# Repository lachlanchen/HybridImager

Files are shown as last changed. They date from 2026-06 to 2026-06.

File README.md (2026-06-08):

[English](README.md) · [العربية](i18n/README.ar.md) · [Español](i18n/README.es.md) · [Français](i18n/README.fr.md) · [日本語](i18n/README.ja.md) · [한국어](i18n/README.ko.md) · [Tiếng Việt](i18n/README.vi.md) · [中文 (简体)](i18n/README.zh-Hans.md) · [中文（繁體）](i18n/README.zh-Hant.md) · [Deutsch](i18n/README.de.md) · [Русский](i18n/README.ru.md)

LazyingArt banner

# HybridImager

*Open hybrid scientific imaging: single-pixel, event, frame, and spectral sensing in one maintainable research stack.*






HybridImager is a research and design workspace for a mixed scientific detector. The concept combines a high-dynamic-range single-pixel bucket detector, event-camera timing, frame-camera texture, and optional spectral measurements under one synchronized data model.

| Donate | PayPal | Stripe |
| --- | --- | --- |
|  |  |  |

## System Concept

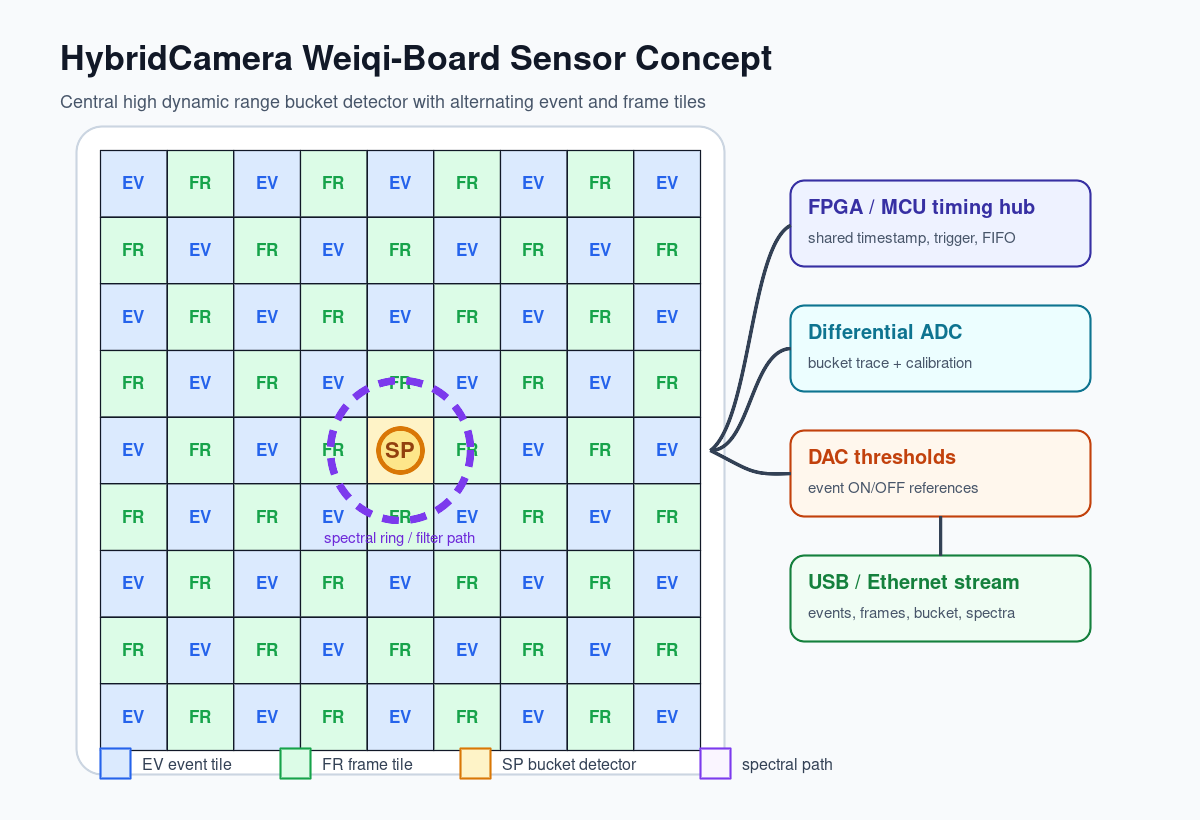
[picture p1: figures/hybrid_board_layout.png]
Hybrid board layout


- **Single-pixel branch:** a central low-noise detector/TIA path for absolute intensity, high dynamic range, and spectral or coded measurements.
- **Event branch:** asynchronous temporal contrast from commercial event cameras first, then open FPGA interfaces when practical.
- **Frame branch:** global-shutter frame modules for texture, calibration, and human-readable inspection.
- **Fusion layer:** timestamped streams with exposure, gain, calibration profile, trigger, and pattern metadata.

## V1 Sensor Board

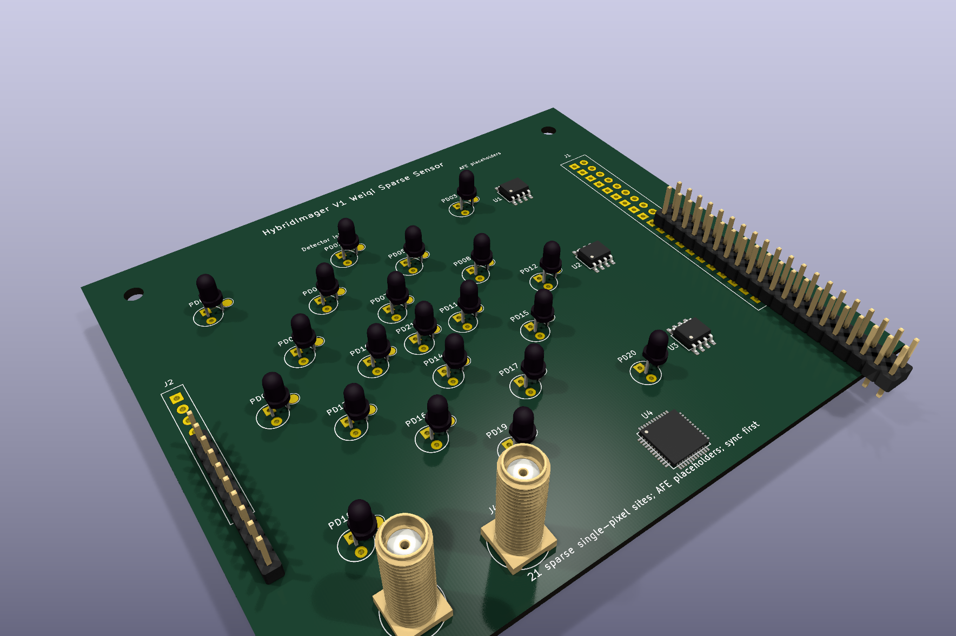
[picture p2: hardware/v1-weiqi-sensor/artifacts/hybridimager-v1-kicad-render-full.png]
HybridImager V1 KiCad render


The first board draft is a KiCad-generated **Weiqi sparse sensor carrier** with 21 single-pixel detector sites, not one central bucket only. It includes per-site signal pads, explicit ground routing, three AFE placeholders, a QFN timing placeholder, SMA sync in/out, power/sync header, and a 2x20 expansion header for later event/frame/tile work.

Review package: [`hardware/v1-weiqi-sensor/`](hardware/v1-weiqi-sensor/) contains the KiCad board, dataset, BOM, clean DRC JSON, STEP model, Gerbers, drill files, and full-view renders.

## V2 ALS-PT19 Matrix

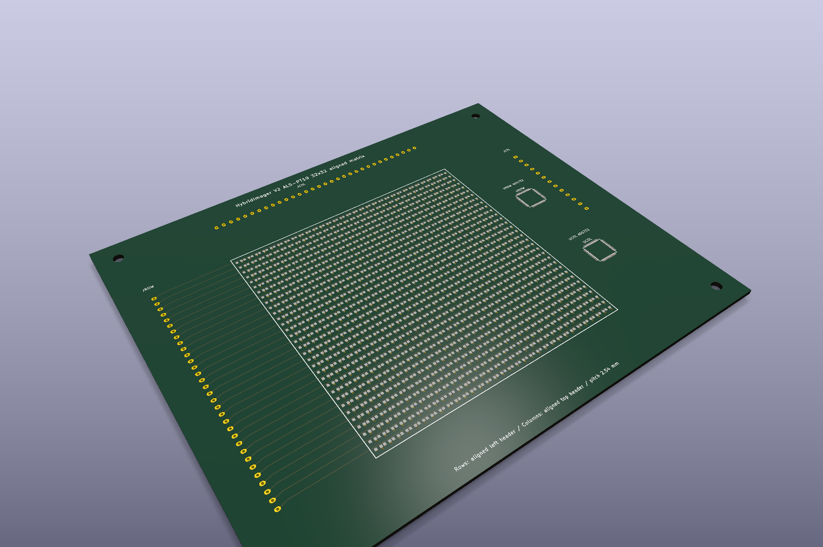
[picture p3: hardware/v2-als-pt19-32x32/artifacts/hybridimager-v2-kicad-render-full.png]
HybridImager V2 KiCad render


V2 is a dense `32x32` sensor-board draft using the `ALS-PT19` phototransistor family from the `CustomSensor`/digiOBSCURA reference. Unlike the older 45-degree, 2.0 mm layout, V2 uses unrotated footprints on a `2.54 mm` pitch so each sensor pad, row header pin, and column header pin is aligned and routable.

Review package: [`hardware/v2-als-pt19-32x32/`](hardware/v2-als-pt19-32x32/) contains the KiCad board, CustomSensor source dataset, BOM, clean DRC JSON, STEP model, Gerbers, drill files, and full-view renders.

## Current Contents

| Area | Location |
| --- | --- |
| Concept paper | `publications/hybrid_camera_concept.pdf` |
| Open camera survey | `publications/open_camera_project_survey.pdf` |
| V1 sparse sensor board | `hardware/v1-weiqi-sensor/` |
| V2 aligned ALS-PT19 matrix | `hardware/v2-als-pt19-32x32/` |
| Research notes | `references/` |
| Deterministic diagrams | `figures/hybrid_board_layout.*`, `figures/hybrid_signal_chain.*` |
| Hardware plan | `hardware/board_architecture.md` |
| Reconstruction plan | `algorithms/reconstruction_plan.md` |
| Prior context | `copied-context/` |
| Open project mirrors | `external/` as git submodules |

## Quick Start

```bash
git clone --recurse-submodules https://github.com/lachlanchen/HybridImager.git
cd HybridImager
make all
```

If the repository is already cloned:

```bash
git submodule update --init --recursive
make survey
```

## Research Baseline

The strongest open single-pixel path is **ONE-PIX** plus **ONE-PIX_hardware**. For event vision, the realistic first build uses commercial event cameras with **OpenEB**, **jAER**, **v2e**, and **E2VID**. For frame hardware, the useful open references are **OneInchEye**, **Antmicro OV9281**, **AXIOM Beta**, and **Seeed reCamera**.

The project does not assume a custom event-sensor ASIC in the first stage. It starts with open board-level synchronization, open data formats, open reconstruction, and reusable mechanical/PCB references.

## CAD And Hardware Notes

Preferred Shapr3D export package for editable mechanical work:

```text
STEP + native .shapr + Parasolid + DXF from sketch + 3MF/STL preview
```

Use STEP as the main interchange format, Parasolid as the high-fidelity solid backup, DXF for 2D outlines and plates, and STL/3MF only for print or mesh preview.

## Build Commands

```bash
make figures   # regenerate deterministic diagrams
make paper     # compile the HybridImager concept paper
make survey    # compile the open camera project survey
make all       # run paper and survey builds
make clean     # remove LaTeX build byproducts
```

## Citation

If you use HybridImager in research, cite the repository. GitHub reads [CITATION.cff](CITATION.cff) and shows a **Cite this repository** panel on the repo page.

```bibtex
@software{chen_hybridimager_2026,
  author = {Chen, Lachlan},
  title = {HybridImager: Open Hybrid Scientific Imaging Research Workspace},
  year = {2026},
  url = {https://github.com/lachlanchen/HybridImager}
}
```

## Status

This is an early research workspace, not a certified imaging product. The immediate goal is a maintainable experiment pipeline for optical and microscopy setups: build with available modules, synchronize cleanly, reconstruct reproducibly, and only integrate custom hardware after the data contract is stable.

Build less. Image more.

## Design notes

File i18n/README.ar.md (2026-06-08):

[English](../README.md) · [العربية](README.ar.md) · [Español](README.es.md) · [Français](README.fr.md) · [日本語](README.ja.md) · [한국어](README.ko.md) · [Tiếng Việt](README.vi.md) · [中文 (简体)](README.zh-Hans.md) · [中文（繁體）](README.zh-Hant.md) · [Deutsch](README.de.md) · [Русский](README.ru.md)

LazyingArt banner

# HybridImager

*تصوير علمي هجين ومفتوح: بكسل واحد، وأحداث، وإطارات، وقياس طيفي ضمن حزمة بحثية قابلة للصيانة.*






HybridImager مساحة بحث وتصميم لكاشف علمي مختلط. يجمع المفهوم بين كاشف بكسل واحد عالي المجال الديناميكي، وتوقيت كاميرا الأحداث، وملمس كاميرا الإطارات، وقياسات طيفية اختيارية ضمن نموذج بيانات متزامن واحد.

| Donate | PayPal | Stripe |
| --- | --- | --- |
|  |  |  |

## مفهوم النظام

Hybrid board layout

- **فرع البكسل الواحد:** مسار كاشف ومضخم TIA منخفض الضجيج للكثافة المطلقة، والمجال الديناميكي العالي، والقياسات الطيفية أو المرمزة.
- **فرع الأحداث:** تباين زمني غير متزامن من كاميرات أحداث تجارية أولا، ثم واجهات FPGA مفتوحة عندما يصبح ذلك عمليا.
- **فرع الإطارات:** وحدات إطارات ذات غالق عام للملمس، والمعايرة، والفحص البشري.
- **طبقة الدمج:** تدفقات ذات طابع زمني مع التعريض، والكسب، وملف المعايرة، والمشغل، وبيانات النمط.

## لوحة المستشعر V1

عرض KiCad لـ HybridImager V1

المسودة الأولى للوحة هي حاملة مستشعرات متناثرة بنمط **Weiqi** مولدة في KiCad، وفيها 21 موقع كاشف بكسل واحد بدلا من bucket مركزي واحد فقط. تتضمن Pads إشارة لكل موقع، ومسار أرضي واضحا، وثلاثة مواضع AFE، وموضع توقيت QFN، وSMA للمزامنة دخولا وخروجا، وموصل طاقة/مزامنة، وموصل توسعة 2x20.

حزمة المراجعة: [`hardware/v1-weiqi-sensor/`](../hardware/v1-weiqi-sensor/) تحتوي لوحة KiCad، ومجموعة البيانات، وBOM، وDRC نظيفا، وSTEP، وGerbers، وملفات الحفر، وعروض الرؤية الكاملة.

## المحتوى الحالي

| المجال | الموقع |
| --- | --- |
| ورقة المفهوم | `publications/hybrid_camera_concept.pdf` |
| مسح مشاريع الكاميرات المفتوحة | `publications/open_camera_project_survey.pdf` |
| لوحة مستشعر متناثرة V1 | `hardware/v1-weiqi-sensor/` |
| مصفوفة ALS-PT19 مصطفة V2 | `hardware/v2-als-pt19-32x32/` |
| ملاحظات البحث | `references/` |
| الرسوم الحتمية | `figures/hybrid_board_layout.*`, `figures/hybrid_signal_chain.*` |
| خطة العتاد | `hardware/board_architecture.md` |
| خطة إعادة البناء | `algorithms/reconstruction_plan.md` |
| سياق سابق | `copied-context/` |
| مرايا المشاريع المفتوحة | `external/` كوحدات git فرعية |

## البدء السريع

```bash
git clone --recurse-submodules https://github.com/lachlanchen/HybridImager.git
cd HybridImager
make all
```

إذا كان المستودع مستنسخا مسبقا:

```bash
git submodule update --init --recursive
make survey
```

## خط الأساس البحثي

أقوى مسار مفتوح للبكسل الواحد هو **ONE-PIX** مع **ONE-PIX_hardware**. ولرؤية الأحداث، يبدأ البناء الواقعي بكاميرات أحداث تجارية مع **OpenEB** و **jAER** و **v2e** و **E2VID**. أما عتاد الإطارات، فأفضل المراجع المفتوحة هي **OneInchEye** و **Antmicro OV9281** و **AXIOM Beta** و **Seeed reCamera**.

لا يفترض المشروع تصنيع ASIC مخصص لحساس الأحداث في المرحلة الأولى. يبدأ بالمزامنة المفتوحة على مستوى اللوحة، وصيغ البيانات المفتوحة، وإعادة البناء القابلة للتكرار، ومراجع ميكانيكية ومراجع PCB قابلة لإعادة الاستخدام.

## ملاحظات CAD والعتاد

حزمة التصدير المفضلة من Shapr3D للعمل الميكانيكي القابل للتحرير:

```text
STEP + native .shapr + Parasolid + DXF from sketch + 3MF/STL preview
```

استخدم STEP كصيغة تبادل رئيسية، وParasolid كنسخة صلبة احتياطية عالية الدقة، وDXF للمخططات ثنائية الأبعاد والصفائح، وSTL/3MF للطباعة أو معاينة الشبكات فقط.

## أوامر البناء

```bash
make figures
make paper
make survey
make all
make clean
```

## الاستشهاد

إذا استخدمت HybridImager في بحثك، فاستشهد بالمستودع. يقرأ GitHub ملف [CITATION.cff](../CITATION.cff) ويعرض لوحة **Cite this repository** في صفحة المستودع.

```bibtex
@software{chen_hybridimager_2026,
  author = {Chen, Lachlan},
  title = {HybridImager: Open Hybrid Scientific Imaging Research Workspace},
  year = {2026},
  url = {https://github.com/lachlanchen/HybridImager}
}
```

## الحالة

هذه مساحة بحث مبكرة وليست منتجا تصويريا معتمدا. الهدف المباشر هو خط تجارب قابل للصيانة للأنظمة البصرية والمجهرية: البناء بوحدات متاحة، والمزامنة النظيفة، وإعادة البناء القابلة للتكرار، ثم دمج العتاد المخصص فقط بعد استقرار عقد البيانات.

ابن أقل. صوّر أكثر.

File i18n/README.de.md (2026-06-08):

[English](../README.md) · [العربية](README.ar.md) · [Español](README.es.md) · [Français](README.fr.md) · [日本語](README.ja.md) · [한국어](README.ko.md) · [Tiếng Việt](README.vi.md) · [中文 (简体)](README.zh-Hans.md) · [中文（繁體）](README.zh-Hant.md) · [Deutsch](README.de.md) · [Русский](README.ru.md)

LazyingArt banner

# HybridImager

*Offene hybride wissenschaftliche Bildgebung: Einzelpixel, Events, Frames und Spektren in einem wartbaren Forschungs-Stack.*






HybridImager ist ein Forschungs- und Design-Arbeitsbereich für einen gemischten wissenschaftlichen Detektor. Das Konzept kombiniert einen Einzelpixel-Bucket-Detektor mit hohem Dynamikumfang, Event-Kamera-Timing, Frame-Kamera-Textur und optionale Spektralmessungen in einem synchronisierten Datenmodell.

| Donate | PayPal | Stripe |
| --- | --- | --- |
|  |  |  |

## Systemkonzept

Hybrid board layout

- **Einzelpixel-Zweig:** zentraler rauscharmer Detektor/TIA-Pfad für absolute Intensität, hohen Dynamikumfang und spektrale oder codierte Messungen.
- **Event-Zweig:** asynchroner zeitlicher Kontrast zuerst mit kommerziellen Event-Kameras, später mit offenen FPGA-Schnittstellen.
- **Frame-Zweig:** Global-Shutter-Module für Textur, Kalibrierung und menschlich lesbare Kontrolle.
- **Fusionsschicht:** Zeitgestempelte Streams mit Belichtung, Gain, Kalibrierprofil, Trigger und Pattern-Metadaten.

## V1-Sensorplatine

HybridImager V1 KiCad-Render

Der erste Platinendraft ist ein in KiCad erzeugter **Weiqi**-Sparse-Sensorträger mit 21 Einzelpixel-Detektorpositionen, nicht nur einem zentralen Bucket. Er enthält Signalpads pro Position, explizite Masseführung, drei AFE-Platzhalter, einen QFN-Timing-Platzhalter, SMA-Sync-Anschlüsse, eine Power/Sync-Stiftleiste und eine 2x20-Erweiterung.

Review-Paket: [`hardware/v1-weiqi-sensor/`](../hardware/v1-weiqi-sensor/) enthält KiCad-Board, Dataset, BOM, sauberen DRC, STEP, Gerbers, Bohrdaten und Vollansicht-Renderings.

## Aktueller Inhalt

| Bereich | Ort |
| --- | --- |
| Konzeptpapier | `publications/hybrid_camera_concept.pdf` |
| Open-Camera-Studie | `publications/open_camera_project_survey.pdf` |
| V1-Sparse-Sensorplatine | `hardware/v1-weiqi-sensor/` |
| V2 ausgerichtete ALS-PT19-Matrix | `hardware/v2-als-pt19-32x32/` |
| Forschungsnotizen | `references/` |
| Deterministische Diagramme | `figures/hybrid_board_layout.*`, `figures/hybrid_signal_chain.*` |
| Hardwareplan | `hardware/board_architecture.md` |
| Rekonstruktionsplan | `algorithms/reconstruction_plan.md` |
| Vorheriger Kontext | `copied-context/` |
| Spiegel offener Projekte | `external/` als git submodules |

## Schnellstart

```bash
git clone --recurse-submodules https://github.com/lachlanchen/HybridImager.git
cd HybridImager
make all
```

Wenn das Repository bereits geklont ist:

```bash
git submodule update --init --recursive
make survey
```

## Forschungsbasis

Der stärkste offene Einzelpixel-Pfad ist **ONE-PIX** plus **ONE-PIX_hardware**. Für Event Vision nutzt der realistische erste Aufbau kommerzielle Event-Kameras mit **OpenEB**, **jAER**, **v2e** und **E2VID**. Für Frame-Hardware sind **OneInchEye**, **Antmicro OV9281**, **AXIOM Beta** und **Seeed reCamera** nützliche offene Referenzen.

Das Projekt setzt in der ersten Phase keinen eigenen Event-Sensor-ASIC voraus. Es beginnt mit offener Board-Synchronisation, offenen Datenformaten, reproduzierbarer Rekonstruktion und wiederverwendbaren Mechanik- und PCB-Referenzen.

## CAD- und Hardware-Hinweise

Bevorzugtes Shapr3D-Exportpaket für editierbare Mechanik:

```text
STEP + native .shapr + Parasolid + DXF from sketch + 3MF/STL preview
```

STEP ist das Hauptaustauschformat, Parasolid die hochgenaue Solid-Sicherung, DXF dient 2D-Konturen und Platten, STL/3MF nur Druck oder Mesh-Vorschau.

## Build-Befehle

```bash
make figures
make paper
make survey
make all
make clean
```

## Zitieren

Wenn Sie HybridImager in Forschung verwenden, zitieren Sie bitte dieses Repository. GitHub liest [CITATION.cff](../CITATION.cff) und zeigt auf der Repository-Seite das Panel **Cite this repository** an.

```bibtex
@software{chen_hybridimager_2026,
  author = {Chen, Lachlan},
  title = {HybridImager: Open Hybrid Scientific Imaging Research Workspace},
  year = {2026},
  url = {https://github.com/lachlanchen/HybridImager}
}
```

## Status

Dies ist ein früher Forschungsarbeitsbereich, kein zertifiziertes Bildgebungsprodukt. Das unmittelbare Ziel ist eine wartbare Experiment-Pipeline für Optik und Mikroskopie: mit verfügbaren Modulen bauen, sauber synchronisieren, reproduzierbar rekonstruieren und kundenspezifische Hardware erst integrieren, wenn der Datenvertrag stabil ist.

Weniger bauen. Mehr abbilden.

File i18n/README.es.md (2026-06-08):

[English](../README.md) · [العربية](README.ar.md) · [Español](README.es.md) · [Français](README.fr.md) · [日本語](README.ja.md) · [한국어](README.ko.md) · [Tiếng Việt](README.vi.md) · [中文 (简体)](README.zh-Hans.md) · [中文（繁體）](README.zh-Hant.md) · [Deutsch](README.de.md) · [Русский](README.ru.md)

LazyingArt banner

# HybridImager

*Imagen científica híbrida y abierta: píxel único, eventos, fotogramas y espectro en una pila de investigación mantenible.*






HybridImager es un espacio de investigación y diseño para un detector científico mixto. Combina un detector de píxel único de alto rango dinámico, temporización de cámara de eventos, textura de cámara de fotogramas y mediciones espectrales opcionales bajo un modelo de datos sincronizado.

| Donate | PayPal | Stripe |
| --- | --- | --- |
|  |  |  |

## Concepto del sistema

Hybrid board layout

- **Rama de píxel único:** detector central y TIA de bajo ruido para intensidad absoluta, alto rango dinámico y mediciones codificadas o espectrales.
- **Rama de eventos:** contraste temporal asíncrono con cámaras comerciales al inicio y luego interfaces FPGA abiertas cuando sea práctico.
- **Rama de fotogramas:** módulos de obturador global para textura, calibración e inspección visual.
- **Capa de fusión:** flujos temporizados con exposición, ganancia, perfil de calibración, disparo y metadatos de patrón.

## Placa sensora V1

Render KiCad de HybridImager V1

El primer borrador de placa es un portador sensor disperso tipo **Weiqi** generado en KiCad, con 21 sitios de detector de píxel único y no un único bucket central. Incluye pads de señal por sitio, retorno de tierra explícito, tres placeholders AFE, un placeholder QFN de temporización, SMA de sincronización, cabecera de alimentación/sync y expansión 2x20.

Paquete de revisión: [`hardware/v1-weiqi-sensor/`](../hardware/v1-weiqi-sensor/) contiene la placa KiCad, dataset, BOM, DRC limpio, STEP, Gerbers, taladros y renders completos.

## Contenido actual

| Área | Ubicación |
| --- | --- |
| Artículo conceptual | `publications/hybrid_camera_concept.pdf` |
| Revisión de cámaras abiertas | `publications/open_camera_project_survey.pdf` |
| Placa sensora dispersa V1 | `hardware/v1-weiqi-sensor/` |
| Matriz ALS-PT19 alineada V2 | `hardware/v2-als-pt19-32x32/` |
| Notas de investigación | `references/` |
| Diagramas deterministas | `figures/hybrid_board_layout.*`, `figures/hybrid_signal_chain.*` |
| Plan de hardware | `hardware/board_architecture.md` |
| Plan de reconstrucción | `algorithms/reconstruction_plan.md` |
| Contexto previo | `copied-context/` |
| Espejos de proyectos abiertos | `external/` como submódulos git |

## Inicio rápido

```bash
git clone --recurse-submodules https://github.com/lachlanchen/HybridImager.git
cd HybridImager
make all
```

Si ya está clonado:

```bash
git submodule update --init --recursive
make survey
```

## Base de investigación

La ruta abierta más sólida para píxel único es **ONE-PIX** con **ONE-PIX_hardware**. Para visión de eventos, el primer prototipo realista usa cámaras comerciales con **OpenEB**, **jAER**, **v2e** y **E2VID**. Para hardware de fotogramas, las referencias abiertas útiles son **OneInchEye**, **Antmicro OV9281**, **AXIOM Beta** y **Seeed reCamera**.

El proyecto no presupone un ASIC personalizado de eventos en la primera etapa. Empieza con sincronización abierta a nivel de placa, formatos de datos abiertos, reconstrucción reproducible y referencias reutilizables de mecánica y PCB.

## Notas CAD y hardware

Paquete de exportación preferido desde Shapr3D para trabajo mecánico editable:

```text
STEP + native .shapr + Parasolid + DXF from sketch + 3MF/STL preview
```

Use STEP como formato principal, Parasolid como respaldo sólido de alta fidelidad, DXF para contornos 2D y placas, y STL/3MF solo para impresión o vista de malla.

## Comandos de compilación

```bash
make figures
make paper
make survey
make all
make clean
```

## Cita

Si usas HybridImager en investigación, cita el repositorio. GitHub lee [CITATION.cff](../CITATION.cff) y muestra el panel **Cite this repository** en la página del repositorio.

```bibtex
@software{chen_hybridimager_2026,
  author = {Chen, Lachlan},
  title = {HybridImager: Open Hybrid Scientific Imaging Research Workspace},
  year = {2026},
  url = {https://github.com/lachlanchen/HybridImager}
}
```

## Estado

Este es un espacio de investigación temprano, no un producto de imagen certificado. El objetivo inmediato es una tubería experimental mantenible para óptica y microscopía: construir con módulos disponibles, sincronizar limpiamente, reconstruir de forma reproducible e integrar hardware personalizado solo cuando el contrato de datos sea estable.

Construye menos. Imagen más.

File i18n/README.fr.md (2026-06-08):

[English](../README.md) · [العربية](README.ar.md) · [Español](README.es.md) · [Français](README.fr.md) · [日本語](README.ja.md) · [한국어](README.ko.md) · [Tiếng Việt](README.vi.md) · [中文 (简体)](README.zh-Hans.md) · [中文（繁體）](README.zh-Hant.md) · [Deutsch](README.de.md) · [Русский](README.ru.md)

LazyingArt banner

# HybridImager

*Imagerie scientifique hybride et ouverte : pixel unique, événements, images et spectre dans une pile de recherche maintenable.*






HybridImager est un espace de recherche et de conception pour un détecteur scientifique mixte. Il associe un détecteur à pixel unique à grande dynamique, le timing d'une caméra événementielle, la texture d'une caméra à images et des mesures spectrales optionnelles dans un même modèle de données synchronisé.

| Donate | PayPal | Stripe |
| --- | --- | --- |
|  |  |  |

## Concept du système

Hybrid board layout

- **Branche pixel unique :** détecteur central et TIA faible bruit pour l'intensité absolue, la grande dynamique et les mesures spectrales ou codées.
- **Branche événementielle :** contraste temporel asynchrone avec des caméras commerciales d'abord, puis des interfaces FPGA ouvertes lorsque cela devient pratique.
- **Branche image :** modules à obturateur global pour la texture, la calibration et l'inspection lisible.
- **Couche de fusion :** flux horodatés avec exposition, gain, profil de calibration, déclenchement et métadonnées de motif.

## Carte capteur V1

Rendu KiCad de HybridImager V1

Le premier brouillon de carte est un support capteur clairsemé de type **Weiqi**, généré avec KiCad, avec 21 sites de détecteur à pixel unique plutôt qu'un seul bucket central. Il inclut des pads de signal par site, un retour de masse explicite, trois emplacements AFE, un emplacement QFN de temporisation, des SMA de synchronisation, un connecteur alimentation/sync et une extension 2x20.

Paquet de revue : [`hardware/v1-weiqi-sensor/`](../hardware/v1-weiqi-sensor/) contient la carte KiCad, le dataset, la BOM, le DRC propre, le STEP, les Gerbers, les perçages et les rendus complets.

## Contenu actuel

| Zone | Emplacement |
| --- | --- |
| Article conceptuel | `publications/hybrid_camera_concept.pdf` |
| Revue des caméras ouvertes | `publications/open_camera_project_survey.pdf` |
| Carte capteur clairsemée V1 | `hardware/v1-weiqi-sensor/` |
| Matrice ALS-PT19 alignée V2 | `hardware/v2-als-pt19-32x32/` |
| Notes de recherche | `references/` |
| Diagrammes déterministes | `figures/hybrid_board_layout.*`, `figures/hybrid_signal_chain.*` |
| Plan matériel | `hardware/board_architecture.md` |
| Plan de reconstruction | `algorithms/reconstruction_plan.md` |
| Contexte antérieur | `copied-context/` |
| Miroirs de projets ouverts | `external/` comme sous-modules git |

## Démarrage rapide

```bash
git clone --recurse-submodules https://github.com/lachlanchen/HybridImager.git
cd HybridImager
make all
```

Si le dépôt est déjà cloné :

```bash
git submodule update --init --recursive
make survey
```

## Base de recherche

La voie ouverte la plus solide pour le pixel unique est **ONE-PIX** avec **ONE-PIX_hardware**. Pour la vision événementielle, le premier montage réaliste utilise des caméras commerciales avec **OpenEB**, **jAER**, **v2e** et **E2VID**. Pour le matériel image, les références ouvertes utiles sont **OneInchEye**, **Antmicro OV9281**, **AXIOM Beta** et **Seeed reCamera**.

Le projet ne suppose pas un ASIC événementiel personnalisé dès la première étape. Il commence par une synchronisation ouverte au niveau carte, des formats de données ouverts, une reconstruction reproductible et des références mécaniques/PCB réutilisables.

## Notes CAD et matériel

Paquet d'export Shapr3D préféré pour le travail mécanique éditable :

```text
STEP + native .shapr + Parasolid + DXF from sketch + 3MF/STL preview
```

Utilisez STEP comme format principal, Parasolid comme sauvegarde solide haute fidélité, DXF pour les contours 2D et les plaques, et STL/3MF seulement pour l'impression ou la prévisualisation de maillage.

## Commandes de construction

```bash
make figures
make paper
make survey
make all
make clean
```

## Citation

Si vous utilisez HybridImager dans une recherche, citez le dépôt. GitHub lit [CITATION.cff](../CITATION.cff) et affiche le panneau **Cite this repository** sur la page du dépôt.

```bibtex
@software{chen_hybridimager_2026,
  author = {Chen, Lachlan},
  title = {HybridImager: Open Hybrid Scientific Imaging Research Workspace},
  year = {2026},
  url = {https://github.com/lachlanchen/HybridImager}
}
```

## Statut

C'est un espace de recherche précoce, pas un produit d'imagerie certifié. L'objectif immédiat est une chaîne expérimentale maintenable pour l'optique et la microscopie : construire avec des modules disponibles, synchroniser proprement, reconstruire de manière reproductible, puis intégrer du matériel personnalisé seulement lorsque le contrat de données est stable.

Construire moins. Imager plus.

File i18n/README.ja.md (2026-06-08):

[English](../README.md) · [العربية](README.ar.md) · [Español](README.es.md) · [Français](README.fr.md) · [日本語](README.ja.md) · [한국어](README.ko.md) · [Tiếng Việt](README.vi.md) · [中文 (简体)](README.zh-Hans.md) · [中文（繁體）](README.zh-Hant.md) · [Deutsch](README.de.md) · [Русский](README.ru.md)

LazyingArt banner

# HybridImager

*単一画素、イベント、フレーム、スペクトル計測を一つの保守しやすい研究スタックにまとめる、オープンなハイブリッド科学イメージング。*






HybridImager は、混合型科学検出器のための研究・設計ワークスペースです。高ダイナミックレンジの単一画素バケット検出器、イベントカメラのタイミング、フレームカメラのテクスチャ、任意のスペクトル測定を、一つの同期データモデルで扱います。

| Donate | PayPal | Stripe |
| --- | --- | --- |
|  |  |  |

## システム概念

Hybrid board layout

- **単一画素ブランチ:** 絶対強度、高ダイナミックレンジ、スペクトルまたは符号化測定のための中央低ノイズ検出器/TIA 経路。
- **イベントブランチ:** まず商用イベントカメラで非同期の時間コントラストを使い、実用化できる段階でオープンな FPGA インターフェイスへ進む。
- **フレームブランチ:** テクスチャ、較正、人が読める確認のためのグローバルシャッターフレームモジュール。
- **融合レイヤー:** 露光、ゲイン、較正プロファイル、トリガー、パターン情報を含むタイムスタンプ付きストリーム。

## V1 センサーボード

HybridImager V1 KiCad レンダー

最初の基板ドラフトは KiCad で生成した **囲碁風の疎なセンサーキャリア**で、中央の bucket 1個だけではなく 21 個の単一画素検出器サイトを持ちます。各サイトの信号パッド、明示的なグラウンド配線、3 個の AFE プレースホルダー、QFN タイミングプレースホルダー、SMA 同期入出力、電源/同期ヘッダー、2x20 拡張ヘッダーを含みます。

レビューパッケージ: [`hardware/v1-weiqi-sensor/`](../hardware/v1-weiqi-sensor/) には KiCad 基板、データセット、BOM、クリーンな DRC、STEP、Gerber、ドリルファイル、全体レンダーが含まれます。

## 現在の内容

| 領域 | 場所 |
| --- | --- |
| コンセプト論文 | `publications/hybrid_camera_concept.pdf` |
| オープンカメラ調査 | `publications/open_camera_project_survey.pdf` |
| V1 疎センサーボード | `hardware/v1-weiqi-sensor/` |
| V2 整列 ALS-PT19 マトリクス | `hardware/v2-als-pt19-32x32/` |
| 研究ノート | `references/` |
| 決定的に生成される図 | `figures/hybrid_board_layout.*`, `figures/hybrid_signal_chain.*` |
| ハードウェア計画 | `hardware/board_architecture.md` |
| 再構成計画 | `algorithms/reconstruction_plan.md` |
| 以前の文脈 | `copied-context/` |
| オープンプロジェクトのミラー | `external/` の git submodule |

## クイックスタート

```bash
git clone --recurse-submodules https://github.com/lachlanchen/HybridImager.git
cd HybridImager
make all
```

すでに clone 済みの場合:

```bash
git submodule update --init --recursive
make survey
```

## 研究ベースライン

単一画素の最も強いオープン経路は **ONE-PIX** と **ONE-PIX_hardware** です。イベントビジョンでは、最初の現実的な構成として商用イベントカメラと **OpenEB**、**jAER**、**v2e**、**E2VID** を使います。フレームハードウェアでは **OneInchEye**、**Antmicro OV9281**、**AXIOM Beta**、**Seeed reCamera** が有用なオープン参照です。

このプロジェクトは初期段階からカスタムイベントセンサー ASIC を前提にしません。まず基板レベルの同期、オープンなデータ形式、再現可能な再構成、再利用できる機械/PCB 参照から始めます。

## CAD とハードウェアの注意

編集可能な機械設計に推奨する Shapr3D の出力:

```text
STEP + native .shapr + Parasolid + DXF from sketch + 3MF/STL preview
```

STEP を主な交換形式、Parasolid を高忠実度のソリッドバックアップ、DXF を 2D 外形や板材用、STL/3MF を印刷またはメッシュプレビュー専用として使います。

## ビルドコマンド

```bash
make figures
make paper
make survey
make all
make clean
```

## 引用

研究で HybridImager を使用する場合は、このリポジトリを引用してください。GitHub は [CITATION.cff](../CITATION.cff) を読み取り、リポジトリページに **Cite this repository** パネルを表示します。

```bibtex
@software{chen_hybridimager_2026,
  author = {Chen, Lachlan},
  title = {HybridImager: Open Hybrid Scientific Imaging Research Workspace},
  year = {2026},
  url = {https://github.com/lachlanchen/HybridImager}
}
```

## 状態

これは初期研究ワークスペースであり、認証済みのイメージング製品ではありません。直近の目的は、光学・顕微鏡実験のための保守可能なパイプラインを作ることです。入手可能なモジュールで構築し、きれいに同期し、再現可能に再構成し、データ契約が安定してから専用ハードウェアを統合します。

少なく作る。もっと撮る。

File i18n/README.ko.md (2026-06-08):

[English](../README.md) · [العربية](README.ar.md) · [Español](README.es.md) · [Français](README.fr.md) · [日本語](README.ja.md) · [한국어](README.ko.md) · [Tiếng Việt](README.vi.md) · [中文 (简体)](README.zh-Hans.md) · [中文（繁體）](README.zh-Hant.md) · [Deutsch](README.de.md) · [Русский](README.ru.md)

LazyingArt banner

# HybridImager

*단일 픽셀, 이벤트, 프레임, 스펙트럼 감지를 하나의 유지 가능한 연구 스택으로 묶는 오픈 하이브리드 과학 이미징.*






HybridImager는 혼합 과학 검출기를 위한 연구 및 설계 작업 공간입니다. 고동적 범위 단일 픽셀 버킷 검출기, 이벤트 카메라 타이밍, 프레임 카메라 텍스처, 선택적 스펙트럼 측정을 하나의 동기화된 데이터 모델로 결합합니다.

| Donate | PayPal | Stripe |
| --- | --- | --- |
|  |  |  |

## 시스템 개념

Hybrid board layout

- **단일 픽셀 브랜치:** 절대 강도, 고동적 범위, 스펙트럼 또는 부호화 측정을 위한 중앙 저잡음 검출기/TIA 경로입니다.
- **이벤트 브랜치:** 먼저 상용 이벤트 카메라로 비동기 시간 대비를 사용하고, 가능해지면 오픈 FPGA 인터페이스로 확장합니다.
- **프레임 브랜치:** 텍스처, 보정, 사람이 확인할 수 있는 검사를 위한 글로벌 셔터 프레임 모듈입니다.
- **퓨전 레이어:** 노출, 게인, 보정 프로파일, 트리거, 패턴 메타데이터를 포함하는 타임스탬프 스트림입니다.

## V1 센서 보드

HybridImager V1 KiCad 렌더

첫 번째 보드 초안은 KiCad로 생성한 **바둑판형 희소 센서 캐리어**이며, 중앙 bucket 하나만이 아니라 21개의 단일 픽셀 검출기 사이트를 둡니다. 사이트별 신호 패드, 명시적 접지 배선, AFE 플레이스홀더 3개, QFN 타이밍 플레이스홀더, SMA 동기 입출력, 전원/동기 헤더, 2x20 확장 헤더를 포함합니다.

검토 패키지: [`hardware/v1-weiqi-sensor/`](../hardware/v1-weiqi-sensor/)에는 KiCad 보드, 데이터셋, BOM, 깨끗한 DRC, STEP, Gerber, 드릴 파일, 전체 렌더가 포함됩니다.

## 현재 내용

| 영역 | 위치 |
| --- | --- |
| 개념 논문 | `publications/hybrid_camera_concept.pdf` |
| 오픈 카메라 조사 | `publications/open_camera_project_survey.pdf` |
| V1 희소 센서 보드 | `hardware/v1-weiqi-sensor/` |
| V2 정렬 ALS-PT19 매트릭스 | `hardware/v2-als-pt19-32x32/` |
| 연구 노트 | `references/` |
| 결정론적 다이어그램 | `figures/hybrid_board_layout.*`, `figures/hybrid_signal_chain.*` |
| 하드웨어 계획 | `hardware/board_architecture.md` |
| 재구성 계획 | `algorithms/reconstruction_plan.md` |
| 이전 맥락 | `copied-context/` |
| 오픈 프로젝트 미러 | `external/` git submodule |

## 빠른 시작

```bash
git clone --recurse-submodules https://github.com/lachlanchen/HybridImager.git
cd HybridImager
make all
```

이미 클론한 경우:

```bash
git submodule update --init --recursive
make survey
```

## 연구 기준선

가장 강한 오픈 단일 픽셀 경로는 **ONE-PIX**와 **ONE-PIX_hardware**입니다. 이벤트 비전의 현실적인 첫 빌드는 상용 이벤트 카메라와 **OpenEB**, **jAER**, **v2e**, **E2VID**를 사용합니다. 프레임 하드웨어에는 **OneInchEye**, **Antmicro OV9281**, **AXIOM Beta**, **Seeed reCamera**가 유용한 오픈 참고 자료입니다.

이 프로젝트는 첫 단계에서 맞춤형 이벤트 센서 ASIC을 전제로 하지 않습니다. 먼저 보드 수준 동기화, 오픈 데이터 형식, 재현 가능한 재구성, 재사용 가능한 기계/PCB 참고 자료에서 시작합니다.

## CAD 및 하드웨어 노트

편집 가능한 기계 작업을 위한 Shapr3D 권장 내보내기 패키지:

```text
STEP + native .shapr + Parasolid + DXF from sketch + 3MF/STL preview
```

STEP은 기본 교환 형식, Parasolid는 고충실도 솔리드 백업, DXF는 2D 외곽선과 판재, STL/3MF는 출력 또는 메시 미리보기 전용으로 사용합니다.

## 빌드 명령

```bash
make figures
make paper
make survey
make all
make clean
```

## 인용

연구에서 HybridImager를 사용한다면 이 저장소를 인용하세요. GitHub는 [CITATION.cff](../CITATION.cff)를 읽어 저장소 페이지에 **Cite this repository** 패널을 표시합니다.

```bibtex
@software{chen_hybridimager_2026,
  author = {Chen, Lachlan},
  title = {HybridImager: Open Hybrid Scientific Imaging Research Workspace},
  year = {2026},
  url = {https://github.com/lachlanchen/HybridImager}
}
```

## 상태

이 저장소는 초기 연구 작업 공간이며 인증된 이미징 제품이 아닙니다. 즉각적인 목표는 광학 및 현미경 실험을 위한 유지 가능한 파이프라인입니다. 사용 가능한 모듈로 만들고, 깨끗하게 동기화하고, 재현 가능하게 재구성하며, 데이터 계약이 안정된 뒤에만 맞춤형 하드웨어를 통합합니다.

덜 만들고, 더 많이 이미징합니다.

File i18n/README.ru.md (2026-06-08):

[English](../README.md) · [العربية](README.ar.md) · [Español](README.es.md) · [Français](README.fr.md) · [日本語](README.ja.md) · [한국어](README.ko.md) · [Tiếng Việt](README.vi.md) · [中文 (简体)](README.zh-Hans.md) · [中文（繁體）](README.zh-Hant.md) · [Deutsch](README.de.md) · [Русский](README.ru.md)

LazyingArt banner

# HybridImager

*Открытая гибридная научная визуализация: один пиксель, события, кадры и спектр в поддерживаемом исследовательском стеке.*






HybridImager — это исследовательская и проектная среда для смешанного научного детектора. Концепция объединяет однопиксельный bucket-детектор с высоким динамическим диапазоном, тайминг событийной камеры, текстуру кадровой камеры и дополнительные спектральные измерения в одной синхронизированной модели данных.

| Donate | PayPal | Stripe |
| --- | --- | --- |
|  |  |  |

## Концепция системы

Hybrid board layout

- **Однопиксельная ветка:** центральный малошумящий детектор/TIA для абсолютной интенсивности, высокого динамического диапазона, спектральных или кодированных измерений.
- **Событийная ветка:** асинхронный временной контраст сначала с коммерческими событийными камерами, затем с открытыми FPGA-интерфейсами.
- **Кадровая ветка:** модули с глобальным затвором для текстуры, калибровки и читаемой проверки.
- **Слой слияния:** потоки с временными метками, экспозицией, усилением, профилем калибровки, триггером и метаданными паттерна.

## Плата датчика V1

KiCad-рендер HybridImager V1

Первый черновик платы — созданный в KiCad разреженный сенсорный носитель типа **Weiqi** с 21 позицией однопиксельных детекторов, а не одним центральным bucket. Он включает сигнальные площадки для каждого сайта, явную разводку земли, три AFE-заготовки, QFN-заготовку тайминга, SMA sync in/out, разъем питания/sync и 2x20 расширение.

Пакет для проверки: [`hardware/v1-weiqi-sensor/`](../hardware/v1-weiqi-sensor/) содержит KiCad-плату, dataset, BOM, чистый DRC, STEP, Gerbers, drill-файлы и полные рендеры.

## Текущее содержимое

| Область | Расположение |
| --- | --- |
| Концептуальная статья | `publications/hybrid_camera_concept.pdf` |
| Обзор открытых камер | `publications/open_camera_project_survey.pdf` |
| Разреженная плата датчика V1 | `hardware/v1-weiqi-sensor/` |
| Выровненная матрица ALS-PT19 V2 | `hardware/v2-als-pt19-32x32/` |
| Исследовательские заметки | `references/` |
| Детерминированные схемы | `figures/hybrid_board_layout.*`, `figures/hybrid_signal_chain.*` |
| План аппаратуры | `hardware/board_architecture.md` |
| План реконструкции | `algorithms/reconstruction_plan.md` |
| Предыдущий контекст | `copied-context/` |
| Зеркала открытых проектов | `external/` как git submodules |

## Быстрый старт

```bash
git clone --recurse-submodules https://github.com/lachlanchen/HybridImager.git
cd HybridImager
make all
```

Если репозиторий уже клонирован:

```bash
git submodule update --init --recursive
make survey
```

## Исследовательская база

Самый сильный открытый путь для однопиксельной системы — **ONE-PIX** плюс **ONE-PIX_hardware**. Для событийного зрения реалистичная первая сборка использует коммерческие событийные камеры с **OpenEB**, **jAER**, **v2e** и **E2VID**. Для кадровой аппаратуры полезны открытые ссылки **OneInchEye**, **Antmicro OV9281**, **AXIOM Beta** и **Seeed reCamera**.

Проект не предполагает собственный ASIC событийного сенсора на первом этапе. Он начинается с открытой синхронизации на уровне платы, открытых форматов данных, воспроизводимой реконструкции и повторно используемых механических/PCB-референсов.

## CAD и аппаратные заметки

Предпочтительный экспорт из Shapr3D для редактируемой механики:

```text
STEP + native .shapr + Parasolid + DXF from sketch + 3MF/STL preview
```

STEP используется как основной формат обмена, Parasolid как высокоточная solid-резервная копия, DXF для 2D-контуров и пластин, а STL/3MF только для печати или просмотра сетки.

## Команды сборки

```bash
make figures
make paper
make survey
make all
make clean
```

## Цитирование

Если вы используете HybridImager в исследовании, процитируйте этот репозиторий. GitHub читает [CITATION.cff](../CITATION.cff) и показывает панель **Cite this repository** на странице репозитория.

```bibtex
@software{chen_hybridimager_2026,
  author = {Chen, Lachlan},
  title = {HybridImager: Open Hybrid Scientific Imaging Research Workspace},
  year = {2026},
  url = {https://github.com/lachlanchen/HybridImager}
}
```

## Статус

Это ранняя исследовательская среда, а не сертифицированный продукт визуализации. Ближайшая цель — поддерживаемый экспериментальный pipeline для оптики и микроскопии: строить из доступных модулей, чисто синхронизировать, воспроизводимо реконструировать и интегрировать кастомную аппаратуру только после стабилизации контракта данных.

Меньше строить. Больше видеть.

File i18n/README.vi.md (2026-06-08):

[English](../README.md) · [العربية](README.ar.md) · [Español](README.es.md) · [Français](README.fr.md) · [日本語](README.ja.md) · [한국어](README.ko.md) · [Tiếng Việt](README.vi.md) · [中文 (简体)](README.zh-Hans.md) · [中文（繁體）](README.zh-Hant.md) · [Deutsch](README.de.md) · [Русский](README.ru.md)

LazyingArt banner

# HybridImager

*Hình ảnh khoa học lai mở: điểm ảnh đơn, sự kiện, khung hình và phổ trong một ngăn xếp nghiên cứu dễ bảo trì.*






HybridImager là không gian nghiên cứu và thiết kế cho một bộ dò khoa học hỗn hợp. Ý tưởng kết hợp bộ dò điểm ảnh đơn có dải động cao, thời gian của camera sự kiện, chi tiết của camera khung hình và phép đo phổ tùy chọn trong một mô hình dữ liệu đồng bộ.

| Donate | PayPal | Stripe |
| --- | --- | --- |
|  |  |  |

## Khái niệm hệ thống

Hybrid board layout

- **Nhánh điểm ảnh đơn:** đường bộ dò trung tâm và TIA nhiễu thấp cho cường độ tuyệt đối, dải động cao, đo phổ hoặc đo mã hóa.
- **Nhánh sự kiện:** tương phản thời gian bất đồng bộ từ camera sự kiện thương mại trước, sau đó là giao diện FPGA mở khi thực tế.
- **Nhánh khung hình:** mô-đun màn trập toàn cục cho chi tiết ảnh, hiệu chuẩn và kiểm tra trực quan.
- **Lớp hợp nhất:** luồng có dấu thời gian với phơi sáng, gain, hồ sơ hiệu chuẩn, trigger và siêu dữ liệu mẫu.

## Bo mạch cảm biến V1

Bản render KiCad HybridImager V1

Bản nháp bo mạch đầu tiên là carrier cảm biến thưa kiểu **Weiqi** được tạo bằng KiCad, có 21 vị trí bộ dò điểm ảnh đơn thay vì chỉ một bucket trung tâm. Nó có pad tín hiệu theo từng vị trí, đường hồi tiếp đất rõ ràng, ba placeholder AFE, một placeholder định thời QFN, SMA sync in/out, header nguồn/sync và header mở rộng 2x20.

Gói rà soát: [`hardware/v1-weiqi-sensor/`](../hardware/v1-weiqi-sensor/) chứa bo KiCad, dataset, BOM, DRC sạch, STEP, Gerber, file khoan và render toàn cảnh.

## Nội dung hiện tại

| Khu vực | Vị trí |
| --- | --- |
| Bài viết ý tưởng | `publications/hybrid_camera_concept.pdf` |
| Khảo sát camera mở | `publications/open_camera_project_survey.pdf` |
| Bo cảm biến thưa V1 | `hardware/v1-weiqi-sensor/` |
| Ma trận ALS-PT19 căn thẳng V2 | `hardware/v2-als-pt19-32x32/` |
| Ghi chú nghiên cứu | `references/` |
| Sơ đồ xác định | `figures/hybrid_board_layout.*`, `figures/hybrid_signal_chain.*` |
| Kế hoạch phần cứng | `hardware/board_architecture.md` |
| Kế hoạch tái tạo | `algorithms/reconstruction_plan.md` |
| Ngữ cảnh trước đó | `copied-context/` |
| Bản sao dự án mở | `external/` dưới dạng git submodule |

## Bắt đầu nhanh

```bash
git clone --recurse-submodules https://github.com/lachlanchen/HybridImager.git
cd HybridImager
make all
```

Nếu đã clone:

```bash
git submodule update --init --recursive
make survey
```

## Nền tảng nghiên cứu

Lộ trình điểm ảnh đơn mở mạnh nhất là **ONE-PIX** cùng **ONE-PIX_hardware**. Với thị giác sự kiện, bản dựng đầu tiên thực tế dùng camera sự kiện thương mại với **OpenEB**, **jAER**, **v2e** và **E2VID**. Với phần cứng khung hình, các tham chiếu mở hữu ích là **OneInchEye**, **Antmicro OV9281**, **AXIOM Beta** và **Seeed reCamera**.

Dự án không giả định ASIC cảm biến sự kiện tùy chỉnh trong giai đoạn đầu. Nó bắt đầu bằng đồng bộ cấp bo mạch mở, định dạng dữ liệu mở, tái tạo có thể lặp lại và tham chiếu cơ khí/PCB có thể tái sử dụng.

## Ghi chú CAD và phần cứng

Gói xuất Shapr3D khuyến nghị cho công việc cơ khí có thể chỉnh sửa:

```text
STEP + native .shapr + Parasolid + DXF from sketch + 3MF/STL preview
```

Dùng STEP làm định dạng trao đổi chính, Parasolid làm bản sao solid độ trung thực cao, DXF cho biên dạng 2D và tấm phẳng, còn STL/3MF chỉ cho in hoặc xem trước mesh.

## Lệnh build

```bash
make figures
make paper
make survey
make all
make clean
```

## Trích dẫn

Nếu dùng HybridImager trong nghiên cứu, hãy trích dẫn kho mã này. GitHub đọc [CITATION.cff](../CITATION.cff) và hiển thị bảng **Cite this repository** trên trang kho mã.

```bibtex
@software{chen_hybridimager_2026,
  author = {Chen, Lachlan},
  title = {HybridImager: Open Hybrid Scientific Imaging Research Workspace},
  year = {2026},
  url = {https://github.com/lachlanchen/HybridImager}
}
```

## Trạng thái

Đây là không gian nghiên cứu giai đoạn đầu, không phải sản phẩm hình ảnh đã được chứng nhận. Mục tiêu trước mắt là một pipeline thí nghiệm dễ bảo trì cho quang học và kính hiển vi: xây bằng mô-đun sẵn có, đồng bộ sạch, tái tạo lặp lại và chỉ tích hợp phần cứng tùy chỉnh sau khi hợp đồng dữ liệu ổn định.

Xây ít hơn. Ghi hình nhiều hơn.

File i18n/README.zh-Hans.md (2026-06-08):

[English](../README.md) · [العربية](README.ar.md) · [Español](README.es.md) · [Français](README.fr.md) · [日本語](README.ja.md) · [한국어](README.ko.md) · [Tiếng Việt](README.vi.md) · [中文 (简体)](README.zh-Hans.md) · [中文（繁體）](README.zh-Hant.md) · [Deutsch](README.de.md) · [Русский](README.ru.md)

LazyingArt banner

# HybridImager

*开放式混合科学成像：把单像素、事件、帧图像和光谱感知放进一个可维护的研究栈。*






HybridImager 是一个面向混合科学探测器的研究与设计工作区。它把高动态范围单像素桶探测器、事件相机时序、帧相机纹理以及可选光谱测量统一到一个同步数据模型中。

| Donate | PayPal | Stripe |
| --- | --- | --- |
|  |  |  |

## 系统概念

Hybrid board layout

- **单像素分支：** 中央低噪声探测器/TIA 通路，用于绝对强度、高动态范围、光谱或编码测量。
- **事件分支：** 先使用商用事件相机获取异步时间对比，再在可行时走向开放 FPGA 接口。
- **帧图像分支：** 全局快门模块提供纹理、标定和可读检查图像。
- **融合层：** 带时间戳的数据流，包含曝光、增益、标定配置、触发和图案元数据。

## V1 传感器板

HybridImager V1 KiCad 渲染

第一版板卡草案是 KiCad 生成的 **围棋式稀疏传感器载板**，包含 21 个单像素探测器位置，而不是只有一个中央 bucket。它包含每个探测点的信号焊盘、明确的接地回流、三个 AFE 占位、一个 QFN 定时占位、SMA 同步输入/输出、电源/同步排针和 2x20 扩展排针。

审查包：[`hardware/v1-weiqi-sensor/`](../hardware/v1-weiqi-sensor/) 包含 KiCad 板、数据集、BOM、干净的 DRC、STEP、Gerber、钻孔文件和完整视角渲染。

## 当前内容

| 区域 | 位置 |
| --- | --- |
| 概念论文 | `publications/hybrid_camera_concept.pdf` |
| 开放相机项目调研 | `publications/open_camera_project_survey.pdf` |
| V1 稀疏传感器板 | `hardware/v1-weiqi-sensor/` |
| V2 对齐 ALS-PT19 矩阵 | `hardware/v2-als-pt19-32x32/` |
| 研究笔记 | `references/` |
| 确定性生成图 | `figures/hybrid_board_layout.*`, `figures/hybrid_signal_chain.*` |
| 硬件计划 | `hardware/board_architecture.md` |
| 重建计划 | `algorithms/reconstruction_plan.md` |
| 既有上下文 | `copied-context/` |
| 开放项目镜像 | `external/` git submodule |

## 快速开始

```bash
git clone --recurse-submodules https://github.com/lachlanchen/HybridImager.git
cd HybridImager
make all
```

如果已经克隆：

```bash
git submodule update --init --recursive
make survey
```

## 研究基线

最可靠的开放单像素路径是 **ONE-PIX** 加 **ONE-PIX_hardware**。事件视觉的现实第一步是使用商用事件相机，并结合 **OpenEB**、**jAER**、**v2e** 和 **E2VID**。帧相机硬件可参考 **OneInchEye**、**Antmicro OV9281**、**AXIOM Beta** 和 **Seeed reCamera**。

项目第一阶段不假设自研事件传感器 ASIC。它从开放的板级同步、开放数据格式、可复现实验重建、可复用机械与 PCB 参考开始。

## CAD 与硬件说明

用于可编辑机械设计的 Shapr3D 推荐导出包：

```text
STEP + native .shapr + Parasolid + DXF from sketch + 3MF/STL preview
```

STEP 作为主要交换格式，Parasolid 作为高保真实体备份，DXF 用于二维轮廓和板件，STL/3MF 仅用于打印或网格预览。

## 构建命令

```bash
make figures
make paper
make survey
make all
make clean
```

## 引用

如果在研究中使用 HybridImager，请引用本仓库。GitHub 会读取 [CITATION.cff](../CITATION.cff)，并在仓库页面显示 **Cite this repository** 面板。

```bibtex
@software{chen_hybridimager_2026,
  author = {Chen, Lachlan},
  title = {HybridImager: Open Hybrid Scientific Imaging Research Workspace},
  year = {2026},
  url = {https://github.com/lachlanchen/HybridImager}
}
```

## 状态

这是早期研究工作区，不是经过认证的成像产品。当前目标是为光学和显微实验建立可维护的流程：用现成模块搭建、干净同步、可重复重建，并在数据契约稳定之后再集成定制硬件。

少造一点，多成像一点。

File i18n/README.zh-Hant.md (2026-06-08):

[English](../README.md) · [العربية](README.ar.md) · [Español](README.es.md) · [Français](README.fr.md) · [日本語](README.ja.md) · [한국어](README.ko.md) · [Tiếng Việt](README.vi.md) · [中文 (简体)](README.zh-Hans.md) · [中文（繁體）](README.zh-Hant.md) · [Deutsch](README.de.md) · [Русский](README.ru.md)

LazyingArt banner

# HybridImager

*開放式混合科學成像：把單像素、事件、影格與光譜感知放進一個可維護的研究堆疊。*






HybridImager 是面向混合科學探測器的研究與設計工作區。它把高動態範圍單像素桶探測器、事件相機時序、影格相機紋理，以及可選光譜測量整合到同一個同步資料模型中。

| Donate | PayPal | Stripe |
| --- | --- | --- |
|  |  |  |

## 系統概念

Hybrid board layout

- **單像素分支：** 中央低雜訊探測器/TIA 通路，用於絕對強度、高動態範圍、光譜或編碼測量。
- **事件分支：** 先以商用事件相機取得非同步時間對比，再在可行時走向開放 FPGA 介面。
- **影格分支：** 全域快門模組提供紋理、校準與可讀檢查影像。
- **融合層：** 帶時間戳的資料流，包含曝光、增益、校準設定、觸發與圖案中繼資料。

## V1 感測器板

HybridImager V1 KiCad 渲染

第一版板卡草案是 KiCad 生成的 **圍棋式稀疏感測器載板**，包含 21 個單像素探測器位置，而不是只有一個中央 bucket。它包含每個探測點的訊號焊盤、明確的接地回流、三個 AFE 佔位、一個 QFN 定時佔位、SMA 同步輸入/輸出、電源/同步排針和 2x20 擴充排針。

審查包：[`hardware/v1-weiqi-sensor/`](../hardware/v1-weiqi-sensor/) 包含 KiCad 板、資料集、BOM、乾淨的 DRC、STEP、Gerber、鑽孔檔和完整視角渲染。

## 目前內容

| 區域 | 位置 |
| --- | --- |
| 概念論文 | `publications/hybrid_camera_concept.pdf` |
| 開放相機專案調研 | `publications/open_camera_project_survey.pdf` |
| V1 稀疏感測器板 | `hardware/v1-weiqi-sensor/` |
| V2 對齊 ALS-PT19 矩陣 | `hardware/v2-als-pt19-32x32/` |
| 研究筆記 | `references/` |
| 確定性生成圖 | `figures/hybrid_board_layout.*`, `figures/hybrid_signal_chain.*` |
| 硬體計畫 | `hardware/board_architecture.md` |
| 重建計畫 | `algorithms/reconstruction_plan.md` |
| 既有脈絡 | `copied-context/` |
| 開放專案鏡像 | `external/` git submodule |

## 快速開始

```bash
git clone --recurse-submodules https://github.com/lachlanchen/HybridImager.git
cd HybridImager
make all
```

如果已經 clone：

```bash
git submodule update --init --recursive
make survey
```

## 研究基線

最可靠的開放單像素路徑是 **ONE-PIX** 加 **ONE-PIX_hardware**。事件視覺的現實第一步是使用商用事件相機，並結合 **OpenEB**、**jAER**、**v2e** 和 **E2VID**。影格相機硬體可參考 **OneInchEye**、**Antmicro OV9281**、**AXIOM Beta** 和 **Seeed reCamera**。

專案第一階段不假設自研事件感測器 ASIC。它從開放的板級同步、開放資料格式、可重複實驗重建、可複用機械與 PCB 參考開始。

## CAD 與硬體說明

用於可編輯機械設計的 Shapr3D 推薦匯出包：

```text
STEP + native .shapr + Parasolid + DXF from sketch + 3MF/STL preview
```

STEP 作為主要交換格式，Parasolid 作為高保真實體備份，DXF 用於二維輪廓和板件，STL/3MF 僅用於列印或網格預覽。

## 建置命令

```bash
make figures
make paper
make survey
make all
make clean
```

## 引用

如果在研究中使用 HybridImager，請引用本倉庫。GitHub 會讀取 [CITATION.cff](../CITATION.cff)，並在倉庫頁面顯示 **Cite this repository** 面板。

```bibtex
@software{chen_hybridimager_2026,
  author = {Chen, Lachlan},
  title = {HybridImager: Open Hybrid Scientific Imaging Research Workspace},
  year = {2026},
  url = {https://github.com/lachlanchen/HybridImager}
}
```

## 狀態

這是早期研究工作區，不是經過認證的成像產品。當前目標是為光學與顯微實驗建立可維護的流程：用現成模組搭建、乾淨同步、可重複重建，並在資料契約穩定之後再整合客製硬體。

少造一點，多成像一點。

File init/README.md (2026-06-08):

# Init Notes

This repository was initialized as a local Git workspace for the HybridCamera experiment.

```bash
mkdir -p HybridCamera/{init,references,publications,figures,hardware,firmware,algorithms,copied-context,scripts}
cd HybridCamera
git init
```

## Copied Local Context

The following related material was copied into `copied-context/` so the hybrid-camera design can be developed without mutating the original repositories:

- `CustomSensor/README.md`
- `CustomSensor/docs/01-firmware-differencing.md`
- `CustomSensor/docs/02-comparator-event-mode.md`
- `CustomSensor/docs/03-bias-and-buffer-upgrade.md`
- `CustomSensor/docs/04-full-event-sensor-redesign.md`
- `CustomSensor/PCB/image_sensor/` schematic and KiCad board files
- `CustomSensor/PCB/mcu/` schematic and KiCad board files
- `CustomSensor/Firmware/` Arduino and Processing sketches
- `NanoMi/README.md`, `NanoMi/AGENTS.md`, and `NanoMi/references/README.md`
- `HYBRID_EM_SENSOR_ROADMAP.AppAutoAction.md`

## Relationship to CustomSensor

`../CustomSensor` already contains a useful first-pass research track for event-like sensing. It proposes:

- Firmware-only temporal differencing.
- Comparator-assisted event detection with the SAMD21 analog comparator.
- TIA/buffer upgrades for the weak muxed phototransistor output.
- Longer-term tiled event-sensor redesign with per-tile comparators and FPGA/MCU capture.

HybridCamera keeps those ideas, but reframes them as one branch of a larger multimodal board. The new work adds a central single-pixel detector, spectral measurements, frame/event fusion, electron-microscopy detector motivation, and a reconstruction pipeline.

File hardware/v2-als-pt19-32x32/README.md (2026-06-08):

# HybridImager V2 ALS-PT19 32x32 Aligned Sensor Board

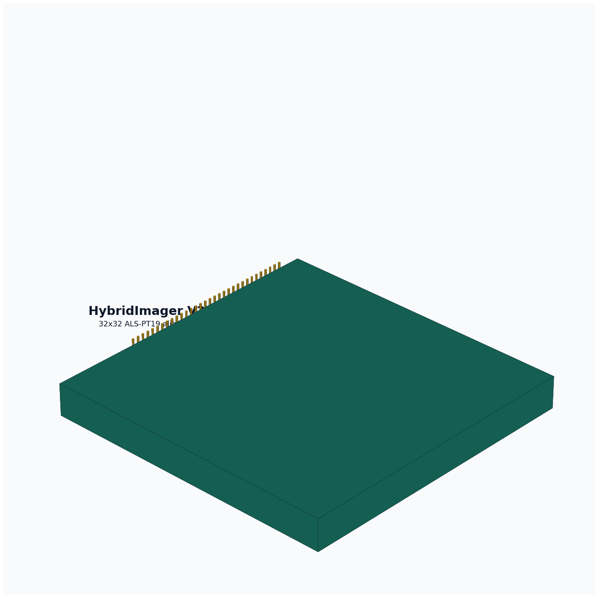
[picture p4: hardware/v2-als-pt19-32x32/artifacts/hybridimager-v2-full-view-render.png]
Full-view concept render


KiCad full board render

V2 moves from the sparse V1 detector carrier to a dense `32x32` matrix using
the same `ALS-PT19` phototransistor family documented in `CustomSensor`.

## What Changed From V1

- `1024` ALS-PT19 detector sites instead of 21 sparse sites.
- Unrotated footprints on a `2.54 mm` pitch so pins are aligned and pads do not overlap.
- Row pins align to the left edge header; column pins align to the top edge header.
- Row nets route horizontally on `F.Cu`; column nets route vertically on `B.Cu`.
- ADG732 row/column mux footprints remain as placement placeholders for the CustomSensor addressing model.

## Files

- `hybridimager-v2-als-pt19-32x32.kicad_pcb`: generated KiCad board.
- `hybridimager-v2-als-pt19-32x32.kicad_pro`: KiCad project file.
- `hybridimager-v2-als-pt19-32x32.kicad_sch`: board-first schematic stub.
- `hybridimager-v2-source-dataset.json`: source assumptions and CustomSensor reference dataset.
- `hybridimager-v2-bom.csv`: draft BOM.
- `artifacts/hybridimager-v2-full-view-render.png`: generated full-view 3D concept render.
- `artifacts/hybridimager-v2-kicad-render-full.png`: KiCad-native zoomed-out render.
- `artifacts/hybridimager-v2-kicad-render-close.png`: KiCad-native closer render.
- `artifacts/hybridimager-v2-als-pt19-32x32.step`: lightweight board-level STEP export.
- `gerber/`: Gerber and drill outputs.

## Reproduce

```bash
python3 scripts/generate_v2_als_pt19_32x32_board.py
kicad-cli pcb upgrade hardware/v2-als-pt19-32x32/hybridimager-v2-als-pt19-32x32.kicad_pcb
kicad-cli pcb drc --format json --severity-all -o hardware/v2-als-pt19-32x32/artifacts/drc.json hardware/v2-als-pt19-32x32/hybridimager-v2-als-pt19-32x32.kicad_pcb
kicad-cli pcb export step --force -o hardware/v2-als-pt19-32x32/artifacts/hybridimager-v2-als-pt19-32x32.step hardware/v2-als-pt19-32x32/hybridimager-v2-als-pt19-32x32.kicad_pcb
kicad-cli pcb export gerbers --layers F.Cu,B.Cu,F.SilkS,B.SilkS,F.Mask,B.Mask,Edge.Cuts,F.Fab,B.Fab --precision 6 --check-zones -o hardware/v2-als-pt19-32x32/gerber hardware/v2-als-pt19-32x32/hybridimager-v2-als-pt19-32x32.kicad_pcb
kicad-cli pcb export drill --generate-map --map-format svg --generate-report --report-path hardware/v2-als-pt19-32x32/artifacts/drill-report.txt -o hardware/v2-als-pt19-32x32/gerber hardware/v2-als-pt19-32x32/hybridimager-v2-als-pt19-32x32.kicad_pcb
xvfb-run -a kicad-cli pcb render --output hardware/v2-als-pt19-32x32/artifacts/hybridimager-v2-kicad-render-full.png --width 1800 --height 1200 --background opaque --quality high --floor --perspective --rotate 315,0,35 --zoom 0.95 hardware/v2-als-pt19-32x32/hybridimager-v2-als-pt19-32x32.kicad_pcb
```

## Engineering Status

Current generated validation: KiCad DRC reports 0 violations and 0 unconnected
items. Full-detail STEP with pad/track solidification is intentionally avoided
for this dense 1024-sensor matrix because it is much slower; use Gerbers for
electrical manufacturing geometry and the lightweight STEP for mechanical board
outline review.

This is a dense matrix layout draft, not a fabrication-approved design. It
still needs final ADG732 schematic wiring, optical masking/baffling decisions,
row/column crosstalk review, solderability review, and firmware pin mapping.

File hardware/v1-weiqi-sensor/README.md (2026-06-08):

# HybridImager V1 Weiqi Sparse Sensor Board

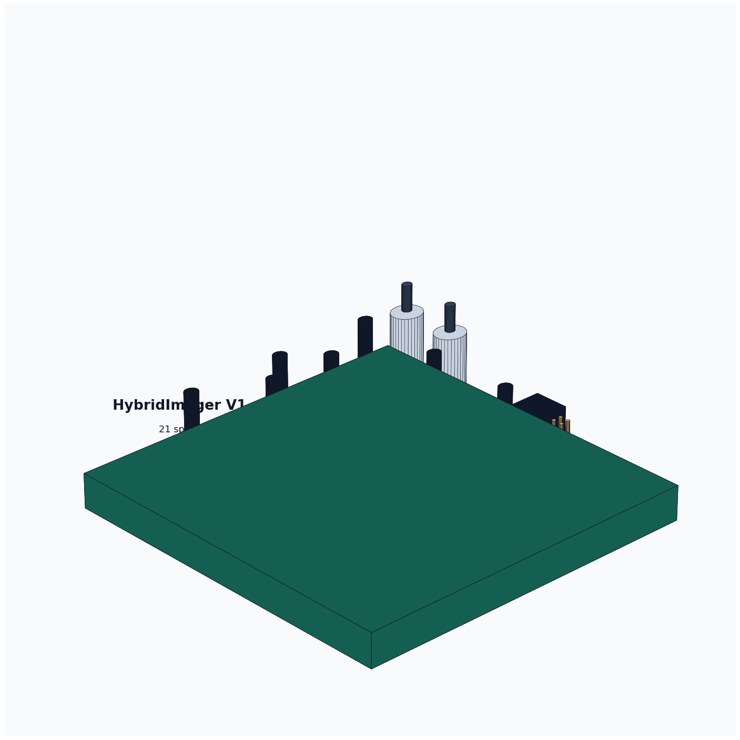
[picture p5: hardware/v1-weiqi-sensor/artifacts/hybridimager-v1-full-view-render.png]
Full-view render


KiCad full board render

This is the first board-level HybridImager sensor draft. It deliberately uses a
**sparse multi-site single-pixel detector array** instead of one central bucket
only. The geometry follows a Weiqi-like 7x7 conceptual grid with 21 populated
detector sites.

## Immediate Scope

- Validate detector spacing and sparse reconstruction geometry.
- Provide per-site signal pads for external TIA/comparator experiments.
- Reserve board area for three TIA banks, one timestamp MCU/FPGA, sync SMA
  connectors, power/sync header, and a 2x20 expansion header.
- Keep V1 buildable and inspectable before committing to dense custom sensor
  electronics or ASIC work.

## Files

- `hybridimager-v1-weiqi-sensor.kicad_pcb`: generated KiCad board.
- `hybridimager-v1-weiqi-sensor.kicad_pro`: KiCad project file.
- `hybridimager-v1-weiqi-sensor.kicad_sch`: board-first schematic stub.
- `hybridimager-v1-source-dataset.json`: source assumptions and design dataset.
- `hybridimager-v1-bom.csv`: draft BOM.
- `artifacts/hybridimager-v1-full-view-render.png`: generated full-view 3D concept render.
- `artifacts/hybridimager-v1-kicad-render-full.png`: KiCad-native zoomed-out render.
- `artifacts/hybridimager-v1-kicad-render-close.png`: KiCad-native closer render.
- `artifacts/hybridimager-v1-weiqi-sensor.step`: STEP export.
- `gerber/`: Gerber and drill outputs.

## Reproduce

```bash
python3 scripts/generate_v1_weiqi_sensor_board.py
kicad-cli pcb upgrade hardware/v1-weiqi-sensor/hybridimager-v1-weiqi-sensor.kicad_pcb
kicad-cli pcb drc --format json --severity-all -o hardware/v1-weiqi-sensor/artifacts/drc.json hardware/v1-weiqi-sensor/hybridimager-v1-weiqi-sensor.kicad_pcb
kicad-cli pcb export step --force --include-pads --include-tracks --include-silkscreen --include-soldermask -o hardware/v1-weiqi-sensor/artifacts/hybridimager-v1-weiqi-sensor.step hardware/v1-weiqi-sensor/hybridimager-v1-weiqi-sensor.kicad_pcb
kicad-cli pcb export gerbers --layers F.Cu,B.Cu,F.SilkS,B.SilkS,F.Mask,B.Mask,Edge.Cuts,F.Fab,B.Fab --precision 6 --check-zones -o hardware/v1-weiqi-sensor/gerber hardware/v1-weiqi-sensor/hybridimager-v1-weiqi-sensor.kicad_pcb
kicad-cli pcb export drill --generate-map --map-format svg --generate-report --report-path hardware/v1-weiqi-sensor/artifacts/drill-report.txt -o hardware/v1-weiqi-sensor/gerber hardware/v1-weiqi-sensor/hybridimager-v1-weiqi-sensor.kicad_pcb
xvfb-run -a kicad-cli pcb render --output hardware/v1-weiqi-sensor/artifacts/hybridimager-v1-kicad-render-full.png --width 1800 --height 1200 --background opaque --quality high --floor --perspective --rotate 315,0,35 --zoom 1.0 hardware/v1-weiqi-sensor/hybridimager-v1-weiqi-sensor.kicad_pcb
```

## Engineering Status

Current generated validation: KiCad DRC reports 0 violations and 0 unconnected
items after running the commands above.

This is still an engineering draft. It is useful for visual review, mechanical
planning, sparse-detector geometry, and next-step analog partitioning. It still
needs a detailed schematic, selected photodiode parts, TIA gain/noise analysis,
layout review, and fabrication review before ordering boards.

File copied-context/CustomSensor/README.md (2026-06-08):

[English](README.md) · [العربية](i18n/README.ar.md) · [Español](i18n/README.es.md) · [Français](i18n/README.fr.md) · [日本語](i18n/README.ja.md) · [한국어](i18n/README.ko.md) · [Tiếng Việt](i18n/README.vi.md) · [中文 (简体)](i18n/README.zh-Hans.md) · [中文（繁體）](i18n/README.zh-Hant.md) · [Deutsch](i18n/README.de.md) · [Русский](i18n/README.ru.md)

LazyingArt banner

# digiOBSCURA - A DIY Image Sensor and Digital Camera 📷










> A fully open DIY imaging stack: custom sensor PCB, MCU board, firmware, webcam viewer, and printable enclosure parts.

## 📚 Table of Contents

- [Overview](#overview)
- [Demo](#demo)
- [Features](#features)
- [Project Structure](#project-structure)
- [Hardware/Firmware Architecture (Current)](#hardwarefirmware-architecture-current)
- [Prerequisites](#prerequisites)
- [Installation](#installation)
- [Usage](#usage)
- [Configuration Notes](#configuration-notes)
- [Examples](#examples)
- [Development Notes](#development-notes)
- [Troubleshooting](#troubleshooting)
- [Roadmap and Technical Notes](#roadmap-and-technical-notes)
- [Contributing](#contributing)
- [Support](#%E2%9D%A4%EF%B8%8F-support)
- [License](#license)

## Overview 🛰️

`digiOBSCURA` is a DIY 32x32 imaging system built around a custom phototransistor array and a SAMD21-based controller.

This repository contains:
- Firmware for standalone camera capture to SD card.
- Firmware + Processing sketch for serial webcam-style live viewing.
- Full KiCad source files for both boards (`image_sensor` and `mcu`) plus production gerbers.
- Mechanical assets (`.f3d`, `.stl`) for enclosure/lens/tripod components.
- Design notes and staged upgrade roadmap documents in [`docs/`](./docs/).

## Quick Snapshot 📌

| Item | Details |
| --- | --- |
| Project size | Camera + firmware + viewer + mechanical design |
| Sensor array | `32x32` (`1024`) custom phototransistor matrix |
| Core controller | `SAMD21G18A` |
| Image output | SD card BMP / serial live frame stream |
| Target workflows | Standalone capture • Webcam-style preview |

## Demo 🎬

Check out the video:

digiOBSCURA Video (https://youtu.be/PaXweP73NT4)

Find the BOM for both boards here: https://www.findchips.com/org/10-open-hardware/list/162969-digiobscura-diy-image-sensor-and-digital-camera

## Features ✨

- 32x32 (1024-pixel) custom phototransistor imaging array.
- Dual ADG732 mux addressing for row/column pixel selection.
- Standalone camera workflow:
  - OLED status UI.
  - Shutter input.
  - SD card output (`DGO_####.bmp`, auto-incremented).
- Webcam workflow:
  - Arduino firmware responds to serial pixel requests at `115200`.
  - Processing app renders a live grayscale 32x32 view.
- Open hardware source:
  - KiCad schematics/PCBs.
  - Production outputs and BOM artifacts.
  - Printable mechanical files.

## Project Structure 🧱

```text
CustomSensor/
|- README.md
|- LICENSE
|- Firmware/
|  |- digiOBSCURA_camera/
|  |  |- digiOBSCURA_camera.ino
|  |- digiOBSCURA_Webcam_Arduino/
|  |  |- digiOBSCURA_Webcam_Arduino.ino
|  `- digiOBSCURA_Webcam_Processing/
|     `- digiOBSCURA_Webcam_Processing.pde
|- docs/
|  |- overview.md
|  |- 01-firmware-differencing.md
|  |- 02-comparator-event-mode.md
|  |- 03-bias-and-buffer-upgrade.md
|  `- 04-full-event-sensor-redesign.md
|- PCB/
|  |- image_sensor/
|  |  |- digiobscura.kicad_pcb
|  |  |- digiobscura.sch
|  |  |- sym-lib-table
|  |  `- fp-lib-table
|  `- mcu/
|     |- digiobscura_mcu.kicad_pcb
|     |- digiobscura_mcu.sch
|     |- sym-lib-table
|     `- fp-lib-table
|- PCB-Production/
|- F3D/
|- STL/
|- logo/
|- i18n/
|- .auto-readme-work/
|  |- pipeline-context.md
|  `- repo-structure-analysis.md
`- .git
```

## Hardware/Firmware Architecture (Current) 🧰

Based on [`docs/overview.md`](./docs/overview.md):

| Subsystem | Details |
|---|---|
| Sensor matrix | `1024 x ALS-PT19` phototransistors |
| Addressing | `2 x ADG732` analog muxes (row + column) |
| Core board | `SAMD21G18A` |
| Power path | `18650` battery, `MCP73831` charger, `3.3 V` regulation |
| Signal path | `OUTCOL` is driven high by MCU GPIO; selected sensor path is read on `OUTROW` via ADC |
| Capture behavior | Camera firmware performs full-frame scans and writes 24-bit BMP files |

## Prerequisites 🧰

### Hardware

- Assembled `image_sensor` and `mcu` boards (or equivalent wiring).
- SAMD21-compatible target board matching pin assignments used in firmware.
- MicroSD card (camera mode).
- `64x48` SSD1306 OLED (camera mode, 4-wire software SPI in current sketch).
- Shutter button/switch input.

### Software

- Arduino IDE (or Arduino CLI) with a SAMD21 board package.
- Required Arduino libraries for camera firmware:
  - `U8g2`
  - `SPI`
  - `SD`
- Processing IDE/runtime for [`Firmware/digiOBSCURA_Webcam_Processing`](./Firmware/digiOBSCURA_Webcam_Processing/).

## Installation 🧩

1. Clone this repository:

```bash

git clone https://github.com/lachlanchen/CustomSensor.git
cd CustomSensor
```

2. Open one firmware sketch in Arduino IDE:
- Camera mode: [`Firmware/digiOBSCURA_camera/digiOBSCURA_camera.ino`](./Firmware/digiOBSCURA_camera/digiOBSCURA_camera.ino)
- Webcam mode: [`Firmware/digiOBSCURA_Webcam_Arduino/digiOBSCURA_Webcam_Arduino.ino`](./Firmware/digiOBSCURA_Webcam_Arduino/digiOBSCURA_Webcam_Arduino.ino)

3. Select the correct SAMD21 board and port, then upload.

4. For webcam mode, open the Processing sketch:
- [`Firmware/digiOBSCURA_Webcam_Processing/digiOBSCURA_Webcam_Processing.pde`](./Firmware/digiOBSCURA_Webcam_Processing/digiOBSCURA_Webcam_Processing.pde)

## Usage 🚀

### Camera Mode (SD snapshot workflow) 📸

1. Flash `digiOBSCURA_camera.ino`.
2. Insert an SD card formatted FAT/FAT32.
3. Power/reset the board; firmware scans for the next free `DGO_####.bmp` filename.
4. Trigger capture with the shutter input.
5. The device captures and writes BMP to SD and shows a thumbnail preview on OLED.

### Webcam Mode (host-rendered live view) 🖥️

1. Flash `digiOBSCURA_Webcam_Arduino.ino`.
2. Connect over USB serial at `115200`.
3. In the Processing sketch, set `String portName` to your actual serial port (the template uses `COM32`).
4. Run Processing sketch; it polls 32x32 pixels and renders a grayscale live frame.

## Configuration Notes 🛠️

Current firmware-level defaults from source:

| Setting | Current value / behavior |
|---|---|
| Resolution | Fixed `32x32` |
| ADC resolution | `analogReadResolution(12)` |
| Camera-mode averaging | `avgCount = 10` (higher quality, lower frame speed) |
| SD CS pin (camera sketch) | `cardPin = 21` |
| Serial baud (webcam path) | `115200` |
| I/O mapping | Hardcoded arrays/variables (`SCOL`, `SROW`, `WR`, `CS`, `EN`, `OUTCOL`, `OUTROW`, etc.) |

If your wiring differs, update pin definitions near the top of each `.ino` file before flashing.

## Examples 🧪

### Open and edit camera firmware

```bash
cd Firmware/digiOBSCURA_camera
# open digiOBSCURA_camera.ino in Arduino IDE
```

### Open and edit the Processing webcam viewer

```bash
cd Firmware/digiOBSCURA_Webcam_Processing
# open digiOBSCURA_Webcam_Processing.pde in Processing IDE
```

### Open PCB sources in KiCad

- `PCB/image_sensor/digiobscura.sch`
- `PCB/image_sensor/digiobscura.kicad_pcb`
- `PCB/mcu/digiobscura_mcu.sch`
- `PCB/mcu/digiobscura_mcu.kicad_pcb`

## Development Notes 📘

- There is no unified build system (`Makefile`, `platformio.ini`, `package.json`, etc.) in this repository.
- Development currently spans Arduino + Processing + KiCad + mechanical CAD files.
- `PCB/image_sensor/README.md` and `PCB/mcu/README.md` currently contain placeholder/template-like content and are not authoritative.
- `i18n/` contains translated README variants; they appear incomplete in places and may lag the English content.

## Troubleshooting 🧯

| Symptom | Checks |
|---|---|
| SD card not detected in camera mode | Confirm wiring and `cardPin` (`21` in current sketch). Reformat SD card (FAT/FAT32) and retry. |
| Blank/noisy image data | Verify `OUTCOL`/`OUTROW` wiring and mux control pins. Check power integrity and sensor board connections. |
| Processing viewer shows no data | Confirm serial baud `115200` in both Arduino and Processing. Update `portName` from `COM32` to your actual port. |
| Very slow capture | Expected with full 32x32 scan and averaging (`avgCount=10` by default). |

## Roadmap and Technical Notes 🗺️

The `docs/` directory tracks planned and exploratory technical directions:

| Document | Focus |
|---|---|
| [`docs/01-firmware-differencing.md`](./docs/01-firmware-differencing.md) | Firmware-only temporal differencing / events |
| [`docs/02-comparator-event-mode.md`](./docs/02-comparator-event-mode.md) | Comparator-assisted event detection |
| [`docs/03-bias-and-buffer-upgrade.md`](./docs/03-bias-and-buffer-upgrade.md) | Analog front-end and bias improvements |
| [`docs/04-full-event-sensor-redesign.md`](./docs/04-full-event-sensor-redesign.md) | Longer-term event-sensor redesign options |

## Contributing 🤝

Contributions are welcome. Suggested contribution areas:

- Hardware bring-up notes and verified pin maps.
- Toolchain/version validation (Arduino core, libraries, Processing version).
- Documentation updates, especially wiring diagrams and calibration workflow.

- `i18n/` README translations once language targets are finalized.

For changes touching hardware or firmware behavior, include:
- Test setup details.
- Board revision context.
- Before/after behavior notes.

## ❤️ Support

| Donate | PayPal | Stripe |
| --- | --- | --- |
| Donate (https://chat.lazying.art/donate) | PayPal (https://paypal.me/RongzhouChen) | Stripe (https://buy.stripe.com/aFadR8gIaflgfQV6T4fw400) |

## License

- `LICENSE` in this repository currently indicates the project is distributed as GPL-3.0 at the repository level.
- Firmware header comments also reference `CC BY-NC-SA 3.0` for some source-header content.

When redistributing binaries, hardware artifacts, or derivatives, verify the exact license conditions in the files you touch and ensure compatibility with your intended use.

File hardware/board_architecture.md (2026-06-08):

# Board Architecture

## Prototype 0: Benchtop Hybrid

Use off-the-shelf modules to validate timing and reconstruction:

- Prophesee/Sony event camera or another OpenEB-compatible event source.
- Global-shutter frame camera.
- Central photodiode plus low-noise TIA and ADC.
- FPGA/MCU timing board for triggers and timestamps.
- Optional filter wheel or spectrometer.

This stage proves the measurement model without designing a dense custom sensor.

## Prototype 1A: V1 Weiqi Sparse Sensor Board

The first generated PCB draft is in [`v1-weiqi-sensor/`](v1-weiqi-sensor/). It is a sensor carrier for sparse single-pixel experiments, not a final integrated imager:

- 21 populated detector sites on a 7x7 conceptual Weiqi grid.
- Per-site signal pads for external TIA/comparator probing.
- Back-copper ground spine tying detector guards, headers, SMA shields, and timing-chip exposed pad.
- Three SOIC-8 AFE placeholders and one QFN-48 MCU/FPGA timing placeholder.
- SMA sync in/out, 1x10 power/sync header, and 2x20 expansion header.

Generated outputs include a clean KiCad DRC report, STEP model, Gerbers, drill files, BOM, source dataset, and full-view 3D renders. This board should be reviewed mechanically and electrically before fabrication, but it is now a concrete V1 artifact for sparse detector geometry and bench wiring.

## Prototype 1B: V2 ALS-PT19 32x32 Matrix

The dense follow-up board is in [`v2-als-pt19-32x32/`](v2-als-pt19-32x32/). It uses the same sensor family documented in `CustomSensor`: `1024 x ALS-PT19` phototransistors with a row/column addressing model inspired by digiOBSCURA.

- 32 rows by 32 columns, all populated.
- Unrotated ALS-PT19 footprints on `2.54 mm` pitch so pads are aligned and do not overlap.
- Row header pins align directly with row buses on `F.Cu`.
- Column header pins align directly with column buses on `B.Cu` through per-pixel vias.
- ADG732 row/column mux footprints are placed as addressing placeholders.

This is the preferred first dense sensor-layout candidate. It still needs final schematic capture for the muxes, analog buffering, optical masking, crosstalk review, and firmware pin mapping before fabrication.

## Prototype 1: DIY Event Tile

Adapt the `CustomSensor` concept into one small tile:

- 4x4 or 8x8 detector matrix.
- Mux or row/column select.
- Per-tile TIA/buffer.
- Comparator with DAC thresholds for ON/OFF events.
- FPGA/MCU timestamp capture.

Success criteria: false-event rate, threshold repeatability, latency, and alignment with frame/bucket channels.

## Prototype 2: Integrated Weiqi Board

Build a square PCB with:

- Central bucket detector aperture.
- Alternating frame/event connectors or tiles.
- Spectral/filter input near the central detector.
- Differential ADC and comparator capture.
- Board-edge trigger/scan connectors for microscope integration.

Use the first board for optics/electronics validation, not final miniaturization.

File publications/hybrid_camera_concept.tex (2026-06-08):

\documentclass[11pt]{article}
\usepackage[margin=1in]{geometry}
\usepackage{graphicx}
\usepackage{booktabs}
\usepackage{hyperref}
\usepackage{amsmath}

\title{HybridCamera: A Weiqi-Board Multimodal Scientific Detector Concept}
\author{Lachlan Chen Research Workspace}
\date{\today}

\begin{document}
\maketitle

\begin{abstract}
HybridCamera is a staged detector concept that combines a central high-dynamic-range single-pixel bucket detector, alternating event and frame-mode tiles, and an optional spectral branch on one synchronized board. The goal is not to immediately fabricate a monolithic event-imager ASIC. The practical first target is a modular board that can be validated with optical scenes, then adapted to NanoMi-style electron microscopy experiments where sparse, high-speed, high-dynamic-range detection is valuable.
\end{abstract}

\section{Motivation}

Frame cameras provide readable texture but waste bandwidth and blur fast dynamics. Event cameras provide sparse temporal contrast with microsecond-class timing but lack static texture and absolute intensity. Single-pixel imaging provides high sensitivity, dynamic range, spectral flexibility, and compressed-sensing compatibility, but needs coded measurements or scan structure. HybridCamera treats these as complementary measurements of the same scene or microscope scan.

The closest architectural precedents are DVS and DAVIS sensors. Lichtsteiner, Posch, and Delbruck demonstrated an asynchronous temporal-contrast sensor with 120 dB dynamic range and 15 us latency. DAVIS later combined DVS events and active-pixel frames in the same pixel array by sharing a photodiode. The proposed board-level design borrows the hybrid idea but keeps each modality modular enough for laboratory iteration.

\section{Weiqi-Board Layout}

The physical concept is a square detector board with a central bucket detector and alternating event/frame tiles around it. The pattern is inspired by a Weiqi board: neighboring positions deliberately hold different capabilities instead of identical pixels.

\begin{figure}[h]
\centering

\caption{Deterministic board layout diagram. EV tiles provide sparse temporal events, FR tiles provide frame texture, SP is the central bucket detector, and the dashed ring denotes a possible spectral/filter path.}
\end{figure}

\IfFileExists{../figures/aginti/hybrid-camera-concept.png}{
\begin{figure}[h]
\centering
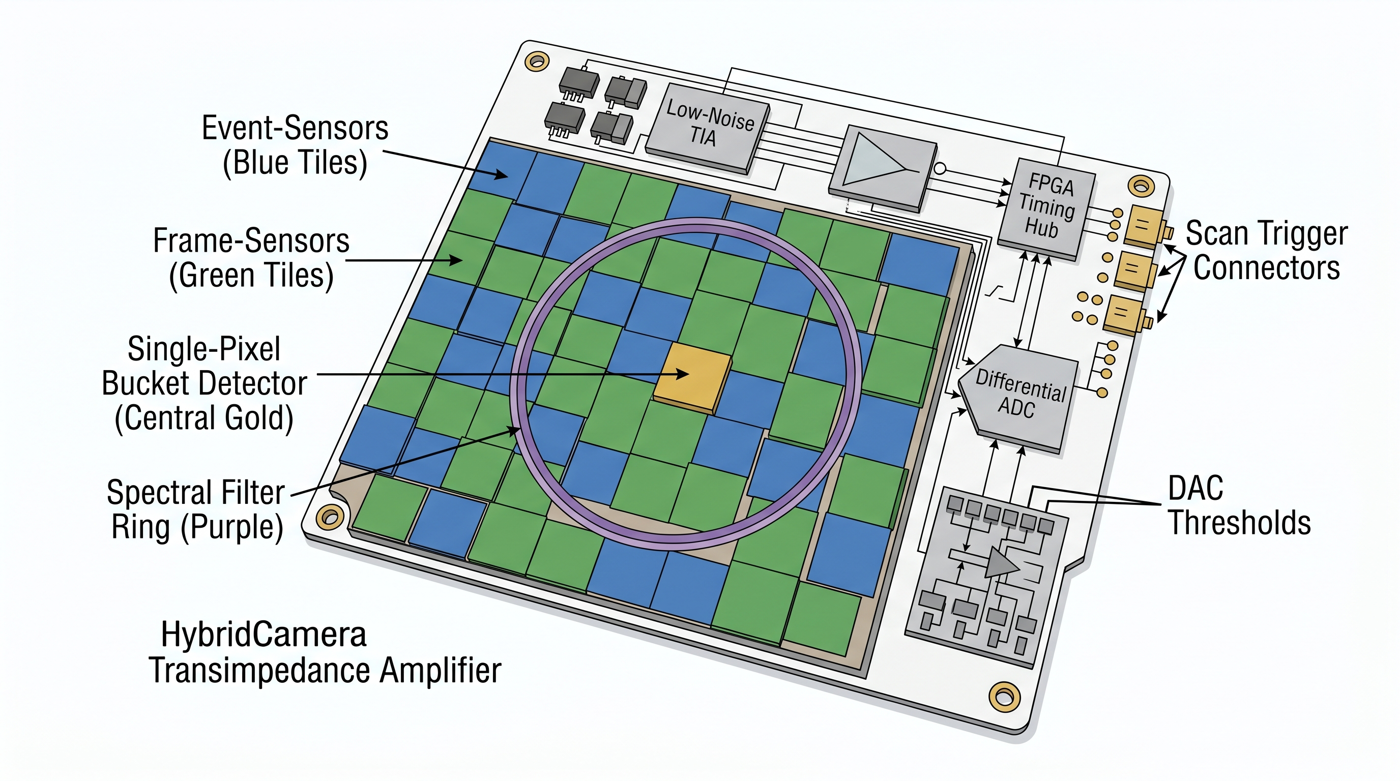
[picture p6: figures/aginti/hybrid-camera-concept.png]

\caption{AgInTi-generated concept image for the hybrid board and laboratory setup.}
\end{figure}
}{}

\section{Electronics}

The central bucket detector should use a low-noise transimpedance amplifier (TIA). The detector and op-amp input must be placed close together, with a guarded summing node, selectable feedback resistor/capacitor pairs, dark calibration, and differential ADC readout. The event path can begin as a tiled comparator system: sample a detector value, compare current and baseline values against DAC thresholds, apply hysteresis, then timestamp ON/OFF events. The frame path should prefer global-shutter triggering so frame exposure aligns with event and bucket measurements.

\begin{figure}[h]
\centering
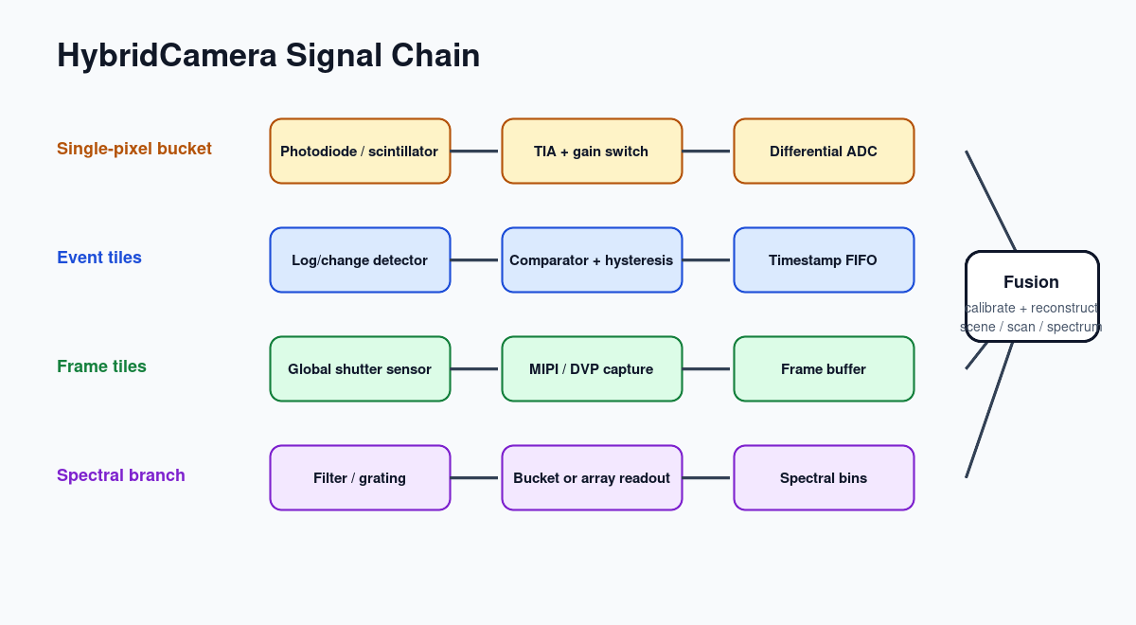
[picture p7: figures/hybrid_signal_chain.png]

\caption{Signal-chain view showing how bucket, event, frame, and spectral measurements enter a common reconstruction stack.}
\end{figure}

\section{Wiring and Control}

All streams need one timestamp authority. A small FPGA or high-speed MCU should own the clock, trigger frame exposure, sample the bucket ADC, capture event IRQs or event buses, tag spectral/filter position, and ingest microscope scan or beam-blanking signals. Each record should carry timestamp, source, gain/exposure metadata, and calibration profile ID.

\section{Reconstruction}

Let \(x\) be the latent scene, scan plane, or diffraction plane. The modalities can be represented as
\[
f_k = M_k x + n_f,\quad
y_t = \phi_t^T x + n_y,\quad
e_i = (u_i,v_i,t_i,p_i),\quad
s_\ell = H_\ell x + n_s.
\]
A baseline offline objective is
\[
\min_x \|M_f x - f\|_2^2
+ \alpha\|\Phi x - y\|_2^2
+ \beta E_{\mathrm{event}}(x,e)
+ \gamma TV(x)
+ \eta\|H x - s\|_2^2.
\]
Frame data anchors texture and geometry, events enforce high-speed temporal consistency, bucket measurements constrain dynamic range and saturation, and spectral measurements separate material or wavelength-dependent contrast.

\section{Prototype Plan}

\begin{tabular}{lll}
\toprule
Stage & Hardware & Success criterion \\
\midrule
0 & Frame camera, event camera, photodiode/TIA & synchronized raw streams \\
1 & DIY 4x4 or 8x8 comparator tile & stable ON/OFF events \\
2 & Integrated board with bucket center & calibrated multimodal reconstruction \\
3 & Microscope scan integration & scan-synchronous detector images \\
\bottomrule
\end{tabular}

\section{Conclusion}

The most useful next step is a modular PCB and simulation stack, not a custom ASIC. Once the board-level timebase, data format, TIA performance, event thresholds, and reconstruction objective are stable, the project can decide which sensing functions deserve integration into a custom tile or chip.

\begin{thebibliography}{9}
\bibitem{dvs} P. Lichtsteiner, C. Posch, and T. Delbruck, ``A 128x128 120 dB 15 us Latency Asynchronous Temporal Contrast Vision Sensor,'' IEEE JSSC, 2008.
\bibitem{survey} G. Gallego et al., ``Event-Based Vision: A Survey,'' IEEE TPAMI, 2022.
\bibitem{davis} C. Brandli et al., ``A 240x180 130dB 3us Latency Global Shutter Spatiotemporal Vision Sensor,'' 2014.
\bibitem{singlepixel} M. P. Edgar, G. M. Gibson, and M. J. Padgett, ``Principles and prospects for single-pixel imaging,'' Nature Photonics, 2019.
\bibitem{edi} L. Pan et al., ``Bringing a Blurry Frame Alive at High Frame-Rate with an Event Camera,'' CVPR, 2019.
\bibitem{nanomi} M. Malac et al., ``NanoMi: an open source electron microscope hardware and software platform,'' 2022.
\bibitem{timepix} D. Jannis et al., ``Event driven 4D STEM acquisition with a Timepix3 detector,'' 2021.
\end{thebibliography}

\end{document}

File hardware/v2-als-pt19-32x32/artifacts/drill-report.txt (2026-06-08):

Drill report for hybridimager-v2-als-pt19-32x32.kicad_pcb
Created on 2026-06-08T12:14:22

Copper Layer Stackup:
    =============================================================
    L1 :  F.Cu                      front
    L2 :  B.Cu                      back

Drill file 'hybridimager-v2-als-pt19-32x32.drl' contains
    plated through holes:
    =============================================================
    T1  0.300mm  0.0118"  (1024 holes))
    T2  0.700mm  0.0276"  (64 holes))
    T3  0.750mm  0.0295"  (13 holes))

    Total plated holes count 1101

Not plated through holes are merged with plated holes
    unplated through holes:
    =============================================================
    T4  3.200mm  0.1260"  (4 holes))

    Total unplated holes count 4

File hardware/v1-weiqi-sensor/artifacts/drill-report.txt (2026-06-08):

Drill report for hybridimager-v1-weiqi-sensor.kicad_pcb
Created on 2026-06-08T11:09:13

Copper Layer Stackup:
    =============================================================
    L1 :  F.Cu                      front
    L2 :  B.Cu                      back

Drill file 'hybridimager-v1-weiqi-sensor.drl' contains
    plated through holes:
    =============================================================
    T1  0.400mm  0.0157"  (1 hole)
    T2  0.800mm  0.0315"  (42 holes))
    T3  0.950mm  0.0374"  (50 holes))
    T4  1.000mm  0.0394"  (8 holes))
    T5  1.300mm  0.0512"  (2 holes))

    Total plated holes count 103

Not plated through holes are merged with plated holes
    unplated through holes:
    =============================================================
    T6  3.200mm  0.1260"  (4 holes))

    Total unplated holes count 4

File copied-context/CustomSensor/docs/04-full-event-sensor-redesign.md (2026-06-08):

# Stage 4 — Full Event-Sensor Redesign

Goal: move toward a DVS-style sensor that emits asynchronous events instead of full frames, with substantially new hardware.

## High-level options
1) **Per-pixel temporal contrast (closest to classic DVS)**
   - Each pixel gets AC coupling + a tiny storage cap and two comparators (ON/OFF). Output is row/col address + polarity when log-intensity crosses thresholds.
   - Requires custom pixel cell and dense routing; beyond the scope of the current PCB and ADG732 muxes.
2) **Row/column shared comparators (practical DIY)**
   - Keep phototransistor matrix, but add per-row and per-column sample/hold plus shared comparators that measure Δ vs a previous frame stored in analog caps.
   - An FPGA/CPLD/microcontroller with analog front-end coordinates sampling, differencing, and emits events.
3) **Segmented sensor with small mux + parallel comparators**
   - Break the array into tiles (e.g., 8×8 blocks). Each tile uses a small mux (8:1) feeding a fast comparator, so scan time per tile is short. Combine events digitally.

## Proposed DIY path (leveraging what exists)
- Respins:
  - Replace ADG732 with smaller 8:1/16:1 muxes per tile to cut address time and reduce charge injection per pixel.
  - Add per-tile op-amp buffer/TIA and a fast comparator with adjustable reference (DAC or resistor ladder).
  - Include a modest FPGA/CPLD (e.g., ICE40UP) or a faster MCU with more timers/DMAs to timestamp events and handle USB.
- Pixel front-end:
  - AC-couple each phototransistor (small series cap) into the comparator input so only changes (dI/dt) pass; provide bias via current source.
  - Set hysteresis/dual thresholds to create ON/OFF events and suppress chatter.
- Data format:
  - Emit `(timestamp, x, y, polarity)` over USB/UART/SD. Use 1–2 byte addresses (32×32 fits in 2 bytes), 1 byte polarity/flags, 4-byte timestamp (µs resolution if possible).

## Risks and mitigations
- Routing density: 1,024 pixels with added analog parts is tight—consider reducing resolution (e.g., 16×16) for the first spin.
- Power/noise: many comparators switching can inject noise; isolate analog and digital grounds, add plenty of decoupling.
- Development load: FPGA toolchain adds complexity; mitigate by using an off-the-shelf dev module for the first prototype and a mezzanine to the sensor PCB.

## Suggested milestones
1) Prototype a single 4×4 or 8×8 tile with AC coupling + comparator + FPGA/MCU capture; validate event generation.
2) Scale to a 16×16 board; measure event rate, false positives, and latency.
3) Integrate SD/USB event logging and a viewer to visualize event clouds in real time.

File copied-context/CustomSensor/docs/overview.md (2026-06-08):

# digiOBSCURA System Overview

## What this project is
- A DIY 32×32 image sensor made from 1,024 ALS-PT19 phototransistors on a dedicated sensor PCB.
- Two ADG732 (32:1) analog multiplexers select one column and one row; their common pins are `OUTCOL` (driven high) and `OUTROW` (analog read).
- A SAMD21G18A MCU board provides power, timing, SD logging, OLED UI, and shutter/buttons. Power: 18650 + MCP73831 charger + 3.3 V LDO.
- Firmware options: camera mode (`Firmware/digiOBSCURA_camera`) saves 32×32 BMPs to SD; webcam mode (`Firmware/digiOBSCURA_Webcam_Arduino` + Processing sketch) streams pixels over serial.

## Key electrical nets and connectors
- Sensor board headers (`PCB/image_sensor/digiobscura.sch`): `J1` (ROW) and `J2` (COL) carry `A0..A4`, `CS`, `WR`, `EN`, `OUTROW`, `OUTCOL`, 3V3, GND.
- Multiplexer control: `A0..A4` set address, `CS` chip select, `WR` write enable, `EN` output enable. Separate nets for ROW and COL muxes.
- Sensing path: GPIO drives `OUTCOL` high; selected phototransistor sinks current; voltage develops at `OUTROW`, read by MCU ADC.
- MCU board breakouts (`J2`/`J3` in `digiobscura_mcu.sch`) map MCU pins to the sensor nets; jumpers/potentiometer near `OUTROW` allow bias tweaking.

## Current firmware behavior (camera mode)
- Select pixel with `pixelSelect(col, row)` → set ADG732 address → strobe `WR`.
- Read `OUTROW` `avgCount` times (default 10) → store in `imgBuff`, track min/max → map to grayscale → write BMP to SD → show thumbnail on OLED.
- Timing: ~10k ADC reads per frame; frame rate is low; no per-session dark/flat calibration.

## Known limitations
- Noise and crosstalk from ADG732 on-resistance and long traces; `OUTCOL` is a stiff GPIO high (not a current source).
- No analog buffering on `OUTROW`; ADC sees mux + sensor impedance directly.
- Dynamic range and speed constrained by averaging and 3.3 V bias; no event/differential readout yet.

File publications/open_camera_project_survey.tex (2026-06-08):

\documentclass[11pt]{article}
\usepackage[margin=1in]{geometry}
\usepackage{booktabs}
\usepackage{hyperref}
\usepackage{array}

\title{Open Single-Pixel, Event, and Image-Sensor Project Survey}
\author{HybridCamera Research Workspace}
\date{\today}

\begin{document}
\maketitle

\begin{abstract}
This survey identifies practical open-source and buyable building blocks for a
hybrid scientific camera that combines a single-pixel bucket detector, event
vision, and frame imaging. The central conclusion is pragmatic: single-pixel
hardware is available in a credible open kit, event-camera software is open but
event-sensor silicon is still commercial, and open frame-camera projects are the
best source of PCB, enclosure, and synchronization patterns.
\end{abstract}

\section{Single-Pixel Camera Projects}

The strongest project found is ONE-PIX, an open single-pixel hyperspectral kit.
It projects coded patterns onto a scene, records the reflected spectrum with a
single detector/spectrometer path, and reconstructs a hyperspectral cube. Its
software repository includes Raspberry Pi control, GUI and CLI workflows,
examples, and plugin interfaces. Its hardware repository includes laser-cut box
plans, STL fixtures, and editable CAD for adapting the instrument. This makes
ONE-PIX the best reference for the HybridCamera bucket/spectral branch.

SPyRiT complements the hardware side. It is a Python toolbox for deep
single-pixel image reconstruction, including neural reconstruction workflows
that can be reused for coded bucket measurements. A small educational
single-pixel-camera demo was also cloned as a minimal reference, but it should
not be treated as the main instrument baseline.

\section{Buying and Sourcing}

For a complete single-pixel system, the best documented option is the premounted
ONE-PIX kit linked from the hardware repository. UPOLabs also lists a DMD-based
single-pixel imaging experiment system intended for teaching and research. For
Taobao-style sourcing, the credible route is usually component sourcing rather
than buying a polished single-pixel camera. The required parts are a DMD or DLP
pattern source, photodiode/APD/PMT detector, low-noise transimpedance amplifier
or lock-in amplifier, synchronized ADC/DAQ, lenses, calibration targets, and a
rigid optical rail or enclosure. TI DLP LightCrafter controller boards are useful
references for the DMD pattern-generation path.

\section{Open Event-Camera Projects}

No mature fully open event-sensor silicon project was found. The practical event
path is to use commercial sensors or cameras with open software layers. OpenEB
is the most important stack because it exposes event-device abstraction,
streaming, visualization, event manipulation, machine-learning utilities, and
Prophesee camera plugins. The Prophesee/Sony IMX636 is a buyable event sensor
family with evaluation kits and published product specifications.

jAER remains important for Address-Event Representation tooling and historical
DVS/DAVIS workflows. v2e is useful before hardware arrives because it converts
normal video into synthetic DVS events. E2VID is useful for reconstruction from
events back to intensity frames. openEye-CamSI is the most relevant open
hardware/gateware project because its roadmap explicitly targets an interface to
an entry-level Prophesee/Sony event imaging sensor and Ethernet transfer.

\section{Open Frame-Camera Hardware}

Open frame-camera projects are more mature than open event-sensor hardware. The
Antmicro OV9281 Dual Camera Board provides KiCad files for two global-shutter
MIPI CSI-2 sensors. OneInchEye provides a Raspberry Pi camera board around the
Sony IMX283 one-inch CMOS sensor, including KiCad and STEP assets. AXIOM Beta
hardware provides a large modular open cinema-camera reference with sensor
front-end boards, enclosure assets, and manufacturing files. Seeed's open
reCamera series is useful as a compact modular AI-camera hardware reference, but
the cloned repository did not verify an event-camera board.

\section{HybridCamera Implications}

\begin{table}[h]
\centering
\small
\begin{tabular}{p{0.22\linewidth}p{0.32\linewidth}p{0.34\linewidth}}
\toprule
Branch & Use now & Later target \\
\midrule
Single-pixel & ONE-PIX plus SPyRiT & Custom bucket detector and coded pattern API \\
Event & OpenEB-capable event camera & openEye-CamSI-style FPGA interface \\
Frame & OV9281, OneInchEye, reCamera, AXIOM references & Triggered global-shutter frame module \\
Fusion & Timestamped stream logs & Shared reconstruction objective across modalities \\
\bottomrule
\end{tabular}
\end{table}

The first HybridCamera prototype should not wait for a custom ASIC. It should
combine a central low-noise bucket detector, a commercial event camera or event
module, and a frame camera under one hardware clock. Each record should include
timestamp, source ID, exposure/gain, calibration profile, trigger metadata, and
the optical pattern or scan position. Once this board-level data contract is
stable, the project can decide whether a custom tile or chip is justified.

\section{Shapr3D Export Guidance}

For mechanical updates, export STEP as the main editable interchange format.
Also export native Shapr3D files as the design archive and Parasolid files as a
high-fidelity solid backup. Export DXF from sketches for 2D plates, optical
mounts, laser-cut profiles, and PCB outline constraints. Export 3MF or STL only
for printing and mesh preview. Export GLB or OBJ only for web previews, Blender
renders, or documentation. IGES is a fallback if STEP fails. PDF, SVG, images,
DWG, JT, and USDZ are useful only when a vendor or viewer specifically requests
them.

The preferred package for this project is therefore: STEP, native Shapr3D,
Parasolid, DXF sketches, and one 3MF or STL preview for each part.

\section{Cloned Reference Set}

\begin{itemize}
\item \texttt{external/one-pix}: single-pixel hyperspectral software.
\item \texttt{external/one-pix-hardware}: ONE-PIX mechanical and build files.
\item \texttt{external/spyrit}: single-pixel reconstruction toolbox.
\item \texttt{external/openeb}: event-camera SDK modules.
\item \texttt{external/event-based-get-started}: event-camera examples.
\item \texttt{external/jaer}: AER/event-camera processing tools.
\item \texttt{external/v2e}: video-to-event simulation.
\item \texttt{external/rpg-e2vid}: event-to-frame reconstruction.
\item \texttt{external/openeye-camsi}: open FPGA camera interface.
\item \texttt{external/one-inch-eye}: open IMX283 frame-camera board.
\item \texttt{external/ov9281-camera-board}: open OV9281 global-shutter board.
\item \texttt{external/axiom-beta-hardware}: modular open camera hardware.
\item \texttt{external/oshw-recamera-series}: modular open AI-camera hardware.
\end{itemize}

\begin{thebibliography}{14}
\bibitem{onepix} PhotonicsOpenProjects, ``ONE-PIX,'' \url{https://github.com/PhotonicsOpenProjects/ONE-PIX}.
\bibitem{onepixhardware} PhotonicsOpenProjects, ``ONE-PIX hardware,'' \url{https://github.com/PhotonicsOpenProjects/ONE-PIX_hardware}.
\bibitem{spyrit} OpenSpyrit, ``SPyRiT,'' \url{https://github.com/openspyrit/spyrit}.
\bibitem{upolabs} UPOLabs, ``Single-pixel imaging experiment system,'' \url{https://www.upolabs.com/ProductsStd_769.html}.
\bibitem{ti} Texas Instruments, ``DLPC900 DLP LightCrafter evaluation module,'' \url{https://www.ti.com/product/DLPLCRC900EVM/part-details/DLPLCRC900EVM}.
\bibitem{openeb} Prophesee, ``OpenEB,'' \url{https://github.com/prophesee-ai/openeb}.
\bibitem{imx636} Prophesee, ``Sony IMX636 co-developed with Prophesee,'' \url{https://www.prophesee.ai/event-based-sensor-imx636-sony-prophesee/}.
\bibitem{jaer} SensorsINI, ``jAER,'' \url{https://github.com/SensorsINI/jaer}.
\bibitem{v2e} SensorsINI, ``v2e,'' \url{https://github.com/SensorsINI/v2e}.
\bibitem{e2vid} UZH RPG, ``E2VID,'' \url{https://github.com/uzh-rpg/rpg_e2vid}.
\bibitem{openeye} chili-chips-ba, ``openEye-CamSI,'' \url{https://github.com/chili-chips-ba/openeye-CamSI}.
\bibitem{ov9281} Antmicro, ``OV9281 Dual Camera Board,'' \url{https://github.com/antmicro/ov9281-camera-board}.
\bibitem{oneincheye} will127534, ``OneInchEye,'' \url{https://github.com/will127534/OneInchEye}.
\bibitem{axiom} apertus open source cinema, ``AXIOM Beta hardware,'' \url{https://github.com/apertus-open-source-cinema/beta-hardware}.
\end{thebibliography}

\end{document}

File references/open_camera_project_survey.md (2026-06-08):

# Open Camera Project Survey

This note records current single-pixel, event-camera, and open image-sensor
projects that are useful for the HybridCamera direction.

## Short Conclusion

The best open single-pixel starting point is **ONE-PIX**: it has acquisition
software, Raspberry Pi control, hyperspectral reconstruction, a hardware
repository, and a premounted commercial kit option. For algorithms, **SPyRiT**
is the best companion because it focuses on single-pixel reconstruction.

For event vision, no mature fully open event-sensor silicon project was found.
The practical path is to buy a commercial event camera or sensor module and use
open software/gateware around it: **OpenEB/Metavision**, **jAER**, **v2e**,
**E2VID**, and **openEye-CamSI**. openEye-CamSI is notable because its roadmap
explicitly targets a Prophesee/Sony event-sensor interface.

For open frame-camera hardware, use projects that expose PCB, enclosure, and
interface design practice around commercial sensors: **AXIOM Beta**, **OneInchEye**,
**Antmicro OV9281 Dual Camera Board**, and **Seeed reCamera**.

## Cloned Repositories

| Path | Role | Notes |
| --- | --- | --- |
| `external/one-pix` | Single-pixel hyperspectral camera software | Open acquisition/control stack with GUI, CLI, plugins, and examples. |
| `external/one-pix-hardware` | Single-pixel kit hardware | Laser-cut case plans, STL fixtures, and editable CAD for the ONE-PIX kit. |
| `external/spyrit` | Single-pixel reconstruction | Deep reconstruction toolbox for simulated and experimental single-pixel data. |
| `external/single-pixel-camera-demo` | Minimal educational demo | Small DIY reference for coded illumination and reconstruction. |
| `external/openeb` | Event-camera SDK core | Open modules for event device HAL, streaming, visualization, ML, and plugins. |
| `external/event-based-get-started` | Event-camera examples | Python/C++ examples for Prophesee Metavision SDK workflows. |
| `external/jaer` | AER/event tooling | Long-lived Java tool stack for DVS/DAVIS-style sensors and AER processing. |
| `external/v2e` | Frame-to-event simulator | Converts normal videos into realistic synthetic DVS event streams. |
| `external/rpg-e2vid` | Event-to-frame reconstruction | Baseline for reconstructing intensity video from event streams. |
| `external/openeye-camsi` | Open camera interface/gateware | Open FPGA camera serial interface; roadmap includes event-camera hardware integration. |
| `external/one-inch-eye` | Open frame camera board | Raspberry Pi IMX283 one-inch CMOS sensor board with KiCad and STEP assets. |
| `external/ov9281-camera-board` | Open global-shutter stereo board | KiCad dual OV9281 MIPI CSI-2 board with open hardware files. |
| `external/axiom-beta-hardware` | Modular open cinema camera | Large open hardware camera stack with sensor boards, PCBs, enclosure, and manufacturing assets. |
| `external/oshw-recamera-series` | Modular AI camera hardware | Open hardware frame-camera system; not verified as an event-camera design in this clone. |

## Buying and Sourcing

**Single-pixel camera:** Start with ONE-PIX if the goal is a real working
research instrument. The hardware repo links to a premounted ONE-PIX kit from
Photonics Bretagne. UPOLabs also lists a single-pixel imaging experiment system
using a DMD spatial light modulator, single-pixel detector, and reconstruction
algorithms. For Taobao sourcing, I found component-style routes more credible
than a turnkey high-quality camera. Search terms to use:

- `单像素成像 实验系统`
- `DMD 空间光调制器`
- `DLP LightCrafter 4500`
- `DLP9500UV DMD`
- `光电探测器 TIA`
- `雪崩光电二极管 模块`
- `光电倍增管 模块`
- `数据采集卡 DAQ`

Minimum component set: DMD/DLP pattern source, photodiode/APD/PMT detector,
low-noise TIA or lock-in amplifier, synchronized ADC/DAQ, lenses, calibration
target, and a rigid optical rail or enclosure.

**Event camera:** Buy a commercial event camera or module first. The IMX636
Prophesee/Sony sensor has 1280 x 720 events, high dynamic range, and EVK options.
Use OpenEB for software, and consider openEye-CamSI if the goal is eventually
to build an open FPGA interface around an event sensor.

**Open image-sensor manufacturing:** I did not find a credible open CMOS image
sensor tapeout project ready for camera use. Open PDKs and open EDA exist, but
image sensors need analog pixels, pinned photodiodes, color/microlens process
steps, dark-current control, packaging, and calibration. For this project, treat
commercial sensors as the physical front end and make the board, synchronization,
data format, calibration, and reconstruction open.

## HybridCamera Design Implications

Use ONE-PIX as the center-bucket/spectral branch reference. Use an OpenEB-capable
event camera for first experiments, then study openEye-CamSI for a future FPGA
event interface. Use OneInchEye, OV9281, AXIOM, and reCamera as mechanical/PCB
examples for frame-camera modules. Keep the HybridCamera data model independent
from any vendor by storing timestamped streams with source ID, exposure/gain,
calibration profile, and hardware trigger metadata.

## Shapr3D Export Preference

Preferred export package for designs you want me to update:

1. `STEP` as the main editable interchange format.
2. Native `.shapr` as the design archive.
3. `Parasolid` (`.x_t` or `.x_b`) as the highest-fidelity solid backup.
4. `DXF from sketch` for flat plates, optical mounts, laser cutting, and PCB
   outline constraints.
5. `3MF` or `STL` for printing/mesh preview only.
6. `GLB` or `OBJ` for web preview, Blender rendering, or documentation only.

Avoid using STL, OBJ, image, PDF, or SVG as the only source for a part that needs
engineering edits. They lose solid CAD history or dimensional intent. IGES is a
fallback if STEP fails. DWG/JT/USDZ are useful only when a manufacturer or viewer
specifically requests them.

For HybridCamera, export **STEP + `.shapr` + Parasolid + DXF sketches + one 3MF
or STL preview** for every mechanical part. That gives enough information for
KiCad 3D placement, FreeCAD/CAD repair, Blender rendering, OpenSCAD reference
geometry, and fabrication checks.

## Source Links

- ONE-PIX: https://github.com/PhotonicsOpenProjects/ONE-PIX
- ONE-PIX hardware: https://github.com/PhotonicsOpenProjects/ONE-PIX_hardware
- SPyRiT: https://github.com/openspyrit/spyrit
- UPOLabs single-pixel imaging system: https://www.upolabs.com/ProductsStd_769.html
- TI DLPC900 DLP controller EVM: https://www.ti.com/product/DLPLCRC900EVM/part-details/DLPLCRC900EVM
- Prophesee OpenEB: https://github.com/prophesee-ai/openeb
- Prophesee/Sony IMX636: https://www.prophesee.ai/event-based-sensor-imx636-sony-prophesee/
- jAER: https://github.com/SensorsINI/jaer
- openEye-CamSI: https://github.com/chili-chips-ba/openeye-CamSI
- Antmicro OV9281 Dual Camera Board: https://github.com/antmicro/ov9281-camera-board
- OneInchEye: https://github.com/will127534/OneInchEye
- AXIOM Beta hardware: https://github.com/apertus-open-source-cinema/beta-hardware
- Seeed OSHW reCamera Series: https://github.com/Seeed-Studio/OSHW-reCamera-Series

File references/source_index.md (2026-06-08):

# Source Index

These sources anchor the current HybridCamera research notes.

## Event and Hybrid Vision

- Lichtsteiner, Posch, Delbruck, "A 128x128 120 dB 15 us Latency Asynchronous Temporal Contrast Vision Sensor": https://tilde.ini.uzh.ch/~tobi/wiki/lib/exe/fetch.php?media=lichtsteiner_dvs_jssc08.pdf
- Gallego et al., "Event-Based Vision: A Survey": https://portal.fis.tum.de/en/publications/event-based-vision-a-survey/
- Brandli et al., DAVIS spatiotemporal vision sensor: https://infoscience.epfl.ch/entities/publication/18690ec7-3340-4648-a9b1-862a9b5673c5
- Prophesee/Sony IMX636 specifications: https://www.prophesee.ai/event-based-sensor-imx636-sony-prophesee/
- OpenEB event-vision framework: https://github.com/prophesee-ai/openeb
- Prophesee event-based getting-started examples: https://github.com/prophesee-ai/event-based-get-started
- jAER Address-Event Representation tools: https://github.com/SensorsINI/jaer
- openEye-CamSI open camera/event interface roadmap: https://github.com/chili-chips-ba/openeye-CamSI

## Single-Pixel and Computational Imaging

- Edgar, Gibson, Padgett, "Principles and prospects for single-pixel imaging": https://www.nature.com/articles/s41566-018-0300-7
- Cascaded compressed-sensing single-pixel camera: https://link.springer.com/article/10.1186/s43074-024-00152-5
- ONE-PIX open single-pixel hyperspectral camera: https://github.com/PhotonicsOpenProjects/ONE-PIX
- ONE-PIX hardware and premounted kit reference: https://github.com/PhotonicsOpenProjects/ONE-PIX_hardware
- SPyRiT single-pixel reconstruction toolbox: https://github.com/openspyrit/spyrit
- UPOLabs DMD single-pixel imaging experiment system: https://www.upolabs.com/ProductsStd_769.html
- TI DLP LightCrafter DLPC900 EVM: https://www.ti.com/product/DLPLCRC900EVM/part-details/DLPLCRC900EVM

## Open Frame-Camera Hardware

- Antmicro OV9281 Dual Camera Board: https://github.com/antmicro/ov9281-camera-board
- OneInchEye Raspberry Pi IMX283 board: https://github.com/will127534/OneInchEye
- AXIOM Beta hardware: https://github.com/apertus-open-source-cinema/beta-hardware
- Seeed OSHW reCamera Series: https://github.com/Seeed-Studio/OSHW-reCamera-Series

## Reconstruction

- Pan et al., EDI frame/event reconstruction: https://openaccess.thecvf.com/content_CVPR_2019/papers/Pan_Bringing_a_Blurry_Frame_Alive_at_High_Frame-Rate_With_an_CVPR_2019_paper.pdf
- E2VID paper: https://vladlen.info/papers/E2VID.pdf
- E2VID code: https://github.com/uzh-rpg/rpg_e2vid

## Detector Electronics and Electron Microscopy

- TI transimpedance compensation note: https://www.ti.com/lit/pdf/sboa055
- TI AN-1803 TIA design considerations: https://www.ti.com/lit/pdf/snoa515
- NanoMi NRC page: https://nrc.canada.ca/en/research-development/nanomi-worlds-first-open-source-transmission-electron-microscope
- NanoMi publication record: https://nrc-publications.canada.ca/eng/view/object/?id=02fb266b-721d-4a35-b825-0af8044db446
- Event-driven Timepix3 4D STEM: https://arxiv.org/abs/2107.02864
- 4D Camera direct electron detector: https://arxiv.org/abs/2305.11961

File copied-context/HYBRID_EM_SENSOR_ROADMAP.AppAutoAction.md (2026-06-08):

# Hybrid Electron-Microscopy Sensor Roadmap

Date: 2026-06-08

## Goal

Build toward an open detector and acquisition stack for a NanoMi-style electron microscope that combines:

- a frame channel for spatial detail and operator context;
- an event channel for sparse, fast changes;
- a single-pixel / bucket-detector channel for high dynamic range and flexible detector physics;
- optional spectral channels for material contrast or optical/scintillator spectroscopy.

The near-term path should be board-level and modular. A true monolithic "frame + event + spectrum + single-pixel" image sensor is a longer-term ASIC/foundry project.

## Local Source Repositories

- `/home/lachlan/ProjectsLFS/NanoMi`: open electron microscope platform, including CAD, electron optics, high-voltage scan electronics, STEM scanner, detector context, and safety constraints.
- `/home/lachlan/ProjectsLFS/CustomSensor`: digiOBSCURA 32x32 phototransistor camera, firmware, KiCad boards, and staged notes for comparator-assisted event mode and full event-sensor redesign.

Use NanoMi as the microscope and detector-interface reference. Use CustomSensor as the first practical custom array, muxing, firmware, and event-readout reference.

## Research Anchors

- NanoMi is a modular open electron microscope platform targeting SEM/TEM/STEM/ED, up to 50 keV, with about 10 nm intended image resolution and UHV-compatible modular optics.
- Event cameras report asynchronous brightness-change events rather than only full frames. Reported advantages include low latency, high temporal resolution, high dynamic range, and lower data rate when scenes are sparse.
- Prophesee's Metavision sensors are a commercial event-sensor reference: each pixel triggers independently, with advertised >120 dB dynamic range and >10k fps time-resolution equivalent.
- DAVIS is the key precedent for hybrid event + frame imaging: it combines DVS events and APS grayscale frames in the same pixel array.
- Single-pixel imaging is relevant because one detector can be paired with structured illumination/scanning/compressive reconstruction, and it can be easier to adapt across spectral bands or unusual detector physics.
- Direct electron detectors are the high-performance EM reference point. They avoid scintillator conversion and can offer far higher sensitivity than scintillator + CCD/CMOS paths, but they raise radiation-hardness, vacuum, packaging, and data-throughput difficulty.

## Proposed Architecture

Start as a modular "Weiqi board" with explicit channels instead of trying to make a custom CMOS sensor first:

```text
NanoMi scan timing / beam state
  -> detector front-end board
      -> frame/scintillator camera input
      -> event/comparator path
      -> single-pixel TIA / bucket detector path
      -> spectral detector or spectrometer input
  -> FPGA or fast MCU timestamp hub
  -> USB/Ethernet data stream
  -> host fusion software
```

Data model:

- Frames: `(frame_id, exposure, timestamp, image)`
- Events: `(timestamp, x, y, polarity, magnitude?)`
- Single-pixel samples: `(timestamp, scan_x, scan_y, detector_value, gain, integration_time)`
- Spectral samples: `(timestamp, scan_x, scan_y, wavelength/bin, intensity)`

## Staged Build Plan

1. **Detector interface audit**
   - Map NanoMi detector locations, scan timing, analog outputs, camera path, and voltage domains.
   - Identify safe external detector ports first; avoid modifying high-voltage or vacuum-critical parts.

2. **Single-pixel detector board**
   - Build a low-noise TIA board for photodiode/PMT/SiPM/scintillator pickup.
   - Synchronize each sample with NanoMi scan coordinates.
   - Validate dark noise, dynamic range, bandwidth, and saturation behavior.

3. **Comparator event mezzanine**
   - Reuse CustomSensor's comparator-event roadmap.
   - Add programmable threshold DACs, hysteresis, event polarity, and timestamp capture.
   - Prototype first on a small 4x4 or 8x8 tile.

4. **Frame + event fusion**
   - Keep a conventional frame/scintillator camera for context.
   - Add event overlay and single-pixel reconstruction in the host software.
   - Store all channels with shared timestamps and calibration metadata.

5. **Spectral branch**
   - Start outside vacuum using scintillator/light-output spectroscopy.
   - Later evaluate electron-energy or optical spectral channels if the microscope geometry supports it.

6. **Custom array respin**
   - Evolve CustomSensor from 32x32 muxed frames to tiled comparators and parallel readout.
   - Candidate blocks: per-tile TIA, comparator, local sample/hold, FPGA timestamping, USB/Ethernet output.

7. **ASIC / direct detector research**
   - Only after board-level proof: consider custom CMOS/event pixel design or partner with a detector foundry.
   - Direct electron exposure requires radiation-hard design and serious packaging/vacuum review.

## Immediate Engineering Requirements

- Keep all high-voltage and vacuum interfaces isolated from early prototypes.
- Add calibration datasets: dark frames, flat fields, comparator thresholds, TIA gain, scan timing, detector geometry.
- Use KiCad project-local libraries and deterministic scripts for every board.
- Export DRC/ERC, Gerbers, drill, STEP, top SVG, close render, and full-board render for review.
- Keep raw microscope captures and large external archives out of git.

## Sources

- NanoMi NRC overview: https://nrc.canada.ca/en/research-development/nanomi-worlds-first-open-source-transmission-electron-microscope
- NanoMi publication abstract: https://nrc-publications.canada.ca/eng/view/object/?id=02fb266b-721d-4a35-b825-0af8044db446
- Event-Based Vision survey: https://research.ibm.com/publications/event-based-vision-a-survey
- Prophesee Metavision sensors: https://www.prophesee.ai/event-based-sensors/
- DAVIS event + frame reference: https://rpg.ifi.uzh.ch/docs/EBCCSP16_Tedaldi.pdf
- Single-pixel imaging review: https://www.nature.com/articles/s41566-018-0300-7
- Direct electron detector glossary: https://www.jeol.com/words/emterms/20160713.103416.php
- 4D Camera direct electron detector: https://arxiv.org/abs/2305.11961
- Cascaded compressed-sensing single-pixel camera: https://link.springer.com/article/10.1186/s43074-024-00152-5

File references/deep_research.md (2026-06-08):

# Deep Research Notes

## Concept

The target device is a hybrid scientific camera/detector that combines four measurement types on one controlled board:

1. **Single-pixel bucket channel** for high dynamic range, lock-in detection, spectroscopy, or electron-counting style intensity integration.
2. **Event channel** for low-latency temporal contrast and sparse high-speed motion/scan changes.
3. **Frame channel** for absolute texture, geometry, calibration, and human-readable preview.
4. **Spectral channel** using filters, grating, scintillator spectrum, or a small spectrometer input.

The proposed pixel organization is "Weiqi-board" inspired: a central bucket detector, surrounded by alternating event and frame tiles. This is easier to prototype than a monolithic custom pixel ASIC because each sensing mode can start as a replaceable module.

## Event Sensors

The classic DVS paper by Lichtsteiner, Posch, and Delbruck describes a 128x128 temporal-contrast CMOS sensor where each pixel independently emits asynchronous events after local relative intensity changes, with 120 dB dynamic range and 15 us latency ([PDF](https://tilde.ini.uzh.ch/~tobi/wiki/lib/exe/fetch.php?media=lichtsteiner_dvs_jssc08.pdf)). The broader event-camera field is summarized by Gallego et al., who emphasize asynchronous sensing, high dynamic range, low latency, and low power ([survey](https://portal.fis.tum.de/en/publications/event-based-vision-a-survey/)).

DAVIS shows the most relevant precedent for this project: it outputs DVS events and global-shutter APS frames concurrently while sharing one photodiode between DVS and APS circuits ([EPFL record](https://infoscience.epfl.ch/entities/publication/18690ec7-3340-4648-a9b1-862a9b5673c5)). Prophesee/Sony IMX636 is a practical commercial reference: 1280x720 event resolution, 4.86 um pixels, less than 100 us latency at 1000 lux, and dynamic range above 86 dB or 120 dB depending on illumination span ([Prophesee](https://www.prophesee.ai/event-based-sensor-imx636-sony-prophesee/)).
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

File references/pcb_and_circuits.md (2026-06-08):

# PCB and Circuit Design

## Board Partition

Design the first PCB as four electrical islands with explicit interfaces:

- **Bucket detector island:** central large-area photodiode, avalanche photodiode, PMT/SiPM adapter, or scintillator-coupled detector.
- **Event tile island:** commercial event module connector or DIY photodiode/comparator tiles.
- **Frame tile island:** global-shutter image sensor module or MIPI/parallel camera board.
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

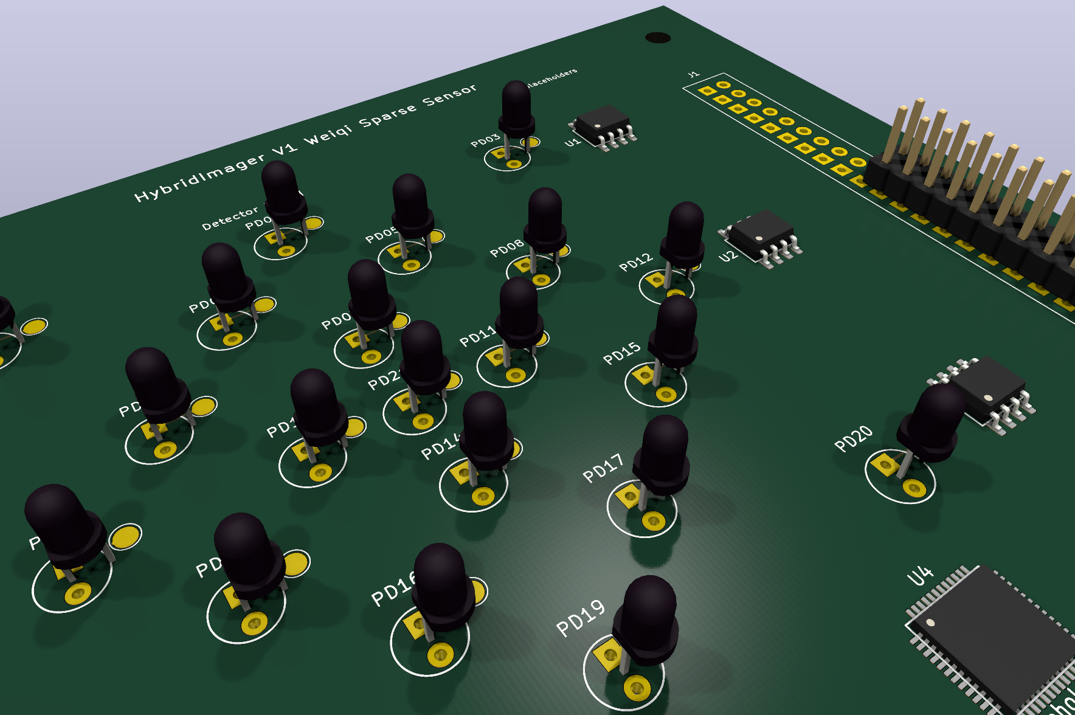
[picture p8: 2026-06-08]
hardware/v1-weiqi-sensor/artifacts/hybridimager-v1-kicad-render-close.png

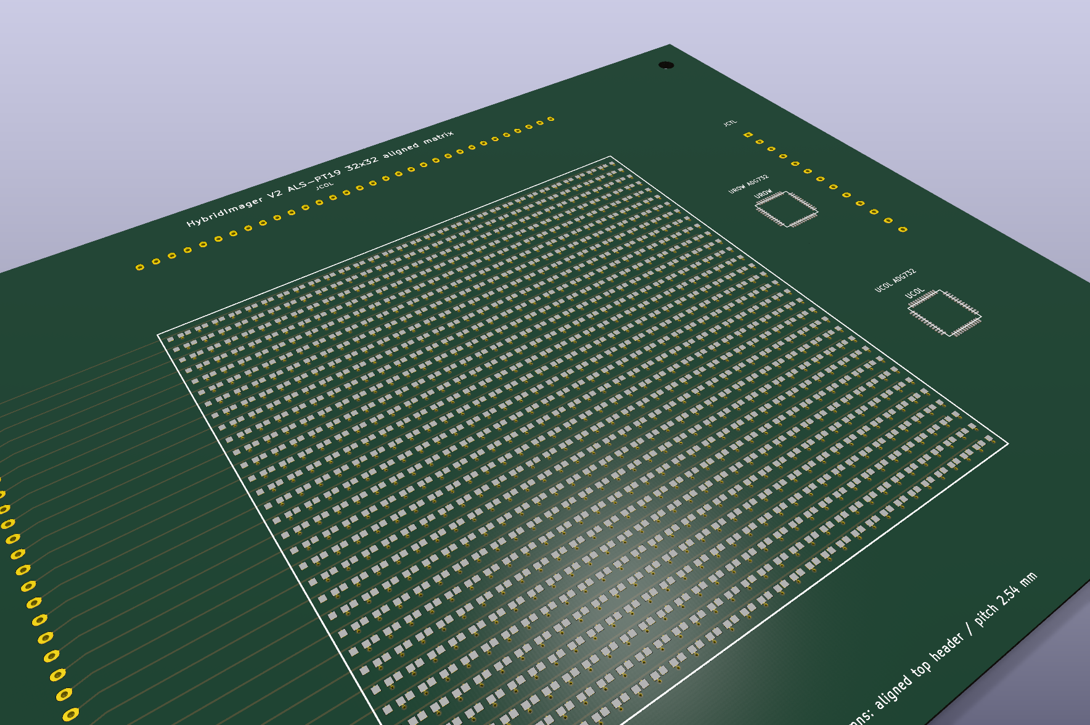
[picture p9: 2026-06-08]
hardware/v2-als-pt19-32x32/artifacts/hybridimager-v2-kicad-render-close.png

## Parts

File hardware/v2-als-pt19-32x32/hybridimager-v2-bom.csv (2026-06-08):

Id | Designator | Quantity | Footprint | Designation | Status
1 | Q0101-Q3232 | 1024 | ALS-PT19 | ALS-PT19 phototransistor | CustomSensor reference
2 | JROW | 1 | Aligned_Row_Header_1x32_2.54mm | Row edge header aligned to sensor rows | draft
3 | JCOL | 1 | Aligned_Col_Header_1x32_2.54mm | Column edge header aligned to sensor columns | draft
4 | JCTL | 1 | Control_Header_1x13_3mm | Address, mux, power, and analog I/O header | draft
5 | UROW,UCOL | 2 | ADG732_TQFP48_PLACEHOLDER | 32:1 row/column analog mux placeholder | not routed
6 | H1-H4 | 4 | M3 NPTH | Mounting holes | draft

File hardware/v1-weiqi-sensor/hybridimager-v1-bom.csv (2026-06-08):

Id | Designator | Quantity | Footprint | Designation | Status
1 | PD01-PD21 | 21 | Sparse_SP_D3_Photodiode | 3 mm photodiode-class sparse single-pixel detector | placeholder
2 | TP01-TP21 | 21 | TP_1.7mm_SMD | Per-site detector signal probe pad | draft
3 | U1-U3 | 3 | SOIC-8 | TIA / comparator AFE placeholder | not valued
4 | U4 | 1 | QFN-48 | MCU/FPGA timestamp placeholder | not valued
5 | J1 | 1 | PinHeader_2x20_P2.54mm | AFE/event expansion header | draft
6 | J2 | 1 | PinHeader_1x10_P2.54mm | Power and sync header | draft
7 | J3,J4 | 2 | Vertical SMA | Sync in/out coax connectors | draft
8 | H1-H4 | 4 | M3 NPTH | Mounting holes | draft

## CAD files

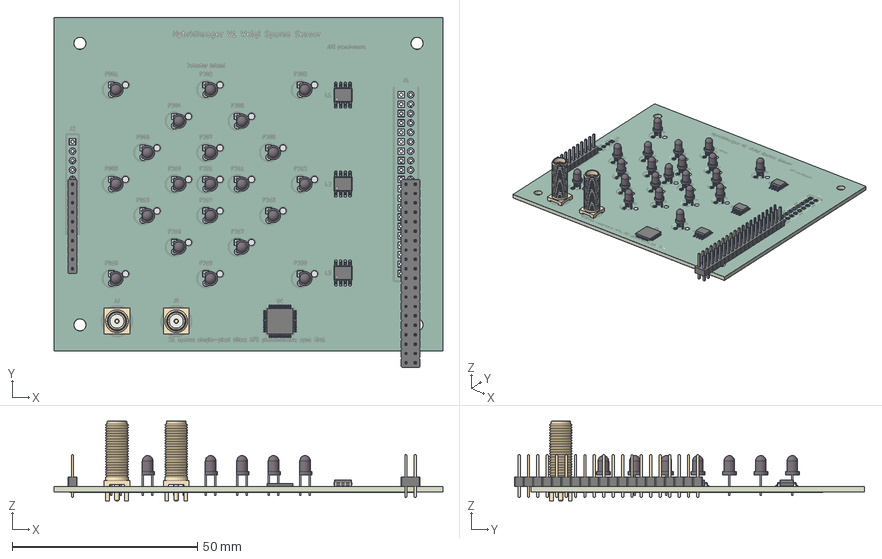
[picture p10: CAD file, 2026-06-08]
hardware/v1-weiqi-sensor/artifacts/hybridimager-v1-weiqi-sensor.step
105.0 x 94.5 x 21.5 mm
LED_D3.0mm_IRBlack x 21
SMA_Amphenol_132291_Vertical x 2
SOIC-8_3.9x4.9mm_P1.27mm x 3
PinHeader_1x10_P254mm_Vertical
PinHeader_2x20_P254mm_Vertical
QFN-48-1EP_7x7mm_Pitch0.5mm
hybridimager-v1-weiqi-sensor_copper
hybridimager-v1-weiqi-sensor_pad
hybridimager-v1-weiqi-sensor_via
hybridimager-v1-weiqi-sensor_silkscreen
hybridimager-v1-weiqi-sensor_soldermask x 2
hybridimager-v1-weiqi-sensor_PCB

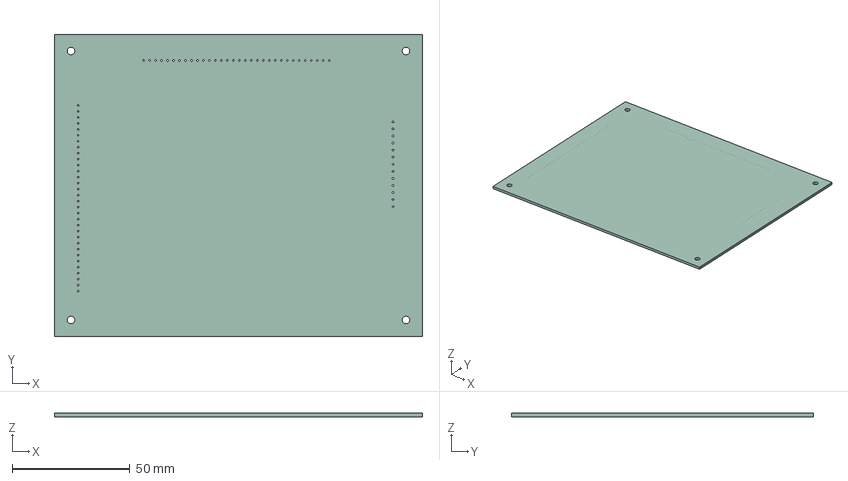
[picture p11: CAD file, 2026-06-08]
hardware/v2-als-pt19-32x32/artifacts/hybridimager-v2-als-pt19-32x32.step
156.0 x 128.0 x 1.51 mm

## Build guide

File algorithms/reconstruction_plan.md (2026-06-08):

# Reconstruction Plan

## Data Products

- `events.parquet` or binary event log: timestamp, x, y, polarity, source.
- `frames/`: raw frames with exposure metadata.
- `bucket.csv`: timestamped ADC samples, gain, bias, dark state.
- `spectral.csv`: wavelength/bin metadata and scalar samples.
- `calibration.json`: geometry, gain, thresholds, timing offsets, and dark/flat corrections.

## Simulation First

Before hardware is finished, generate synthetic data from a known image/video:

1. Downsample a frame sequence to the proposed tile geometry.
2. Generate DVS-like events from log-intensity threshold crossings.
3. Generate Hadamard or random single-pixel measurements.
4. Add realistic read noise, dark current, threshold mismatch, and timing jitter.
5. Evaluate reconstruction against the known source.

## Reconstruction Stack

- Use NumPy/SciPy for the first physics-based solver.
- Add PyTorch for learned E2VID/SPyRiT-style branches.
- Store experiments as scripts plus JSON configs so a hardware run can be replayed.

## Minimal Solver

Start with frame and bucket fusion:

```python
# x is a vectorized image estimate
loss = frame_weight * norm(M @ x - frame) ** 2
loss += bucket_weight * norm(Phi @ x - bucket) ** 2
loss += tv_weight * total_variation(x)
```

Then add event constraints once timestamps and thresholds are calibrated.

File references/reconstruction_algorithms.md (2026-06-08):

# Reconstruction Algorithms

## Measurement Model

Represent the unknown scene, scan plane, or diffraction plane as `x`. HybridCamera records several coupled measurements:

```text
frame:        f_k = M_k x + noise
single-pixel: y_t = phi_t^T x + noise
events:       e_i = (u_i, v_i, t_i, p_i), triggered when Delta log I crosses +/- C
spectral:     s_l = H_l x + noise
```

The frame channel anchors texture and absolute geometry. The event channel supplies high-temporal-resolution changes. The bucket channel supplies high dynamic range scalar constraints. The spectral branch adds wavelength or energy contrast.

## Baseline Pipeline

1. Calibrate dark current, flat field, event thresholds, ADC gains, and geometric alignment.
2. Convert events into time surfaces or event frames for preview.
3. Reconstruct single-pixel images using Hadamard/compressed-sensing matrices.
4. Fuse events with frame anchors using an EDI-style physical model or E2VID-style learned reconstruction.
5. Add bucket measurements as global consistency constraints.
6. Add spectral bins as separate channels or low-rank abundance maps.

## Optimization Form

A practical offline objective is:

```text
min_x  ||M_f x - f||_2^2
     + alpha ||Phi x - y||_2^2
     + beta  E_event(x, e)
     + gamma TV(x)
     + eta   ||H x - s||_2^2
```

`E_event` can enforce that predicted log-intensity changes match event polarities and timestamps. `TV(x)` or wavelet sparsity stabilizes undersampled single-pixel reconstruction.

## Algorithms to Reuse

- **OpenEB / Metavision examples:** event decoding, time surfaces, visualization, filtering, and live camera integration.
- **E2VID:** learned event-to-video reconstruction, useful when a dense preview is needed from sparse event streams.
- **EDI:** high-frame-rate video reconstruction from a blurry/intensity frame plus events.
- **SPyRiT:** single-pixel reconstruction and deep reconstruction baselines.
- **4D STEM sparse processing:** event/electron-counting style storage and reconstruction ideas for microscope detector modes.

## Reconstruction Milestones

1. Simulate synthetic frames, events, and bucket samples from one video or scan image.
2. Recover `x` from bucket-only Hadamard measurements.
3. Recover a high-speed preview from frame plus events.
4. Add bucket constraints to reduce drift and recover saturated/dark regions.
5. Add spectral channels and evaluate on calibration targets.
6. Move to microscope scan data: reconstruct scalar detector images, event maps, and diffraction/spectrum-informed overlays.

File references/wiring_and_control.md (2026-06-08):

# Wiring and Control

## Timing Model

All modalities need one shared timebase. Use an FPGA or high-speed MCU timer as the timestamp authority, then synchronize:

- Event packets from event sensor or comparator tiles.
- Frame exposure start/end.
- ADC samples from the bucket detector.
- Spectral/filter position or wavelength index.
- Microscope scan coordinates, beam blanking, and dwell clock.

Target data records should include `timestamp_ns`, `source`, `x`, `y`, `polarity`, `value`, `gain`, `exposure`, and `calibration_id` where applicable.

## Physical Wiring

- **Bucket detector:** guarded coax or short PCB trace into the TIA; optional reverse-bias supply; differential ADC output to controller.
- **Event module:** MIPI, USB3, or parallel event bus if commercial; GPIO event IRQ and SPI/I2C configuration if DIY.
- **Frame module:** MIPI CSI-2 or parallel DVP into FPGA/SBC; global shutter trigger line preferred.
- **Spectral branch:** filter-wheel UART/I2C, grating motor driver, or spectrometer trigger/USB.
- **Microscope branch:** isolated trigger input, scan X/Y sample, beam blank, and detector gate lines.

## Firmware State Machine

1. Load calibration profile and detector gain table.
2. Arm the global clock and clear event/frame/ADC FIFOs.
3. Trigger frame exposure and bucket integration.
4. Stream events continuously.
5. On each scan dwell or pattern step, tag bucket samples with scan/pattern ID.
6. Flush records into a chunked file format such as HDF5/Zarr or a simple binary log plus JSON sidecar.

## Control Interfaces

The prototype can expose a Python control layer:

```python
camera.set_bucket_gain("10M")
camera.set_event_threshold(on=0.12, off=-0.12)
camera.trigger_frame(exposure_us=500)
camera.start_scan_sync(source="external_ttl")
camera.record("runs/sample_001")
```

For live work, publish reduced streams first: event count map, latest frame, bucket trace, and reconstructed preview. Store raw streams for offline reconstruction and calibration.

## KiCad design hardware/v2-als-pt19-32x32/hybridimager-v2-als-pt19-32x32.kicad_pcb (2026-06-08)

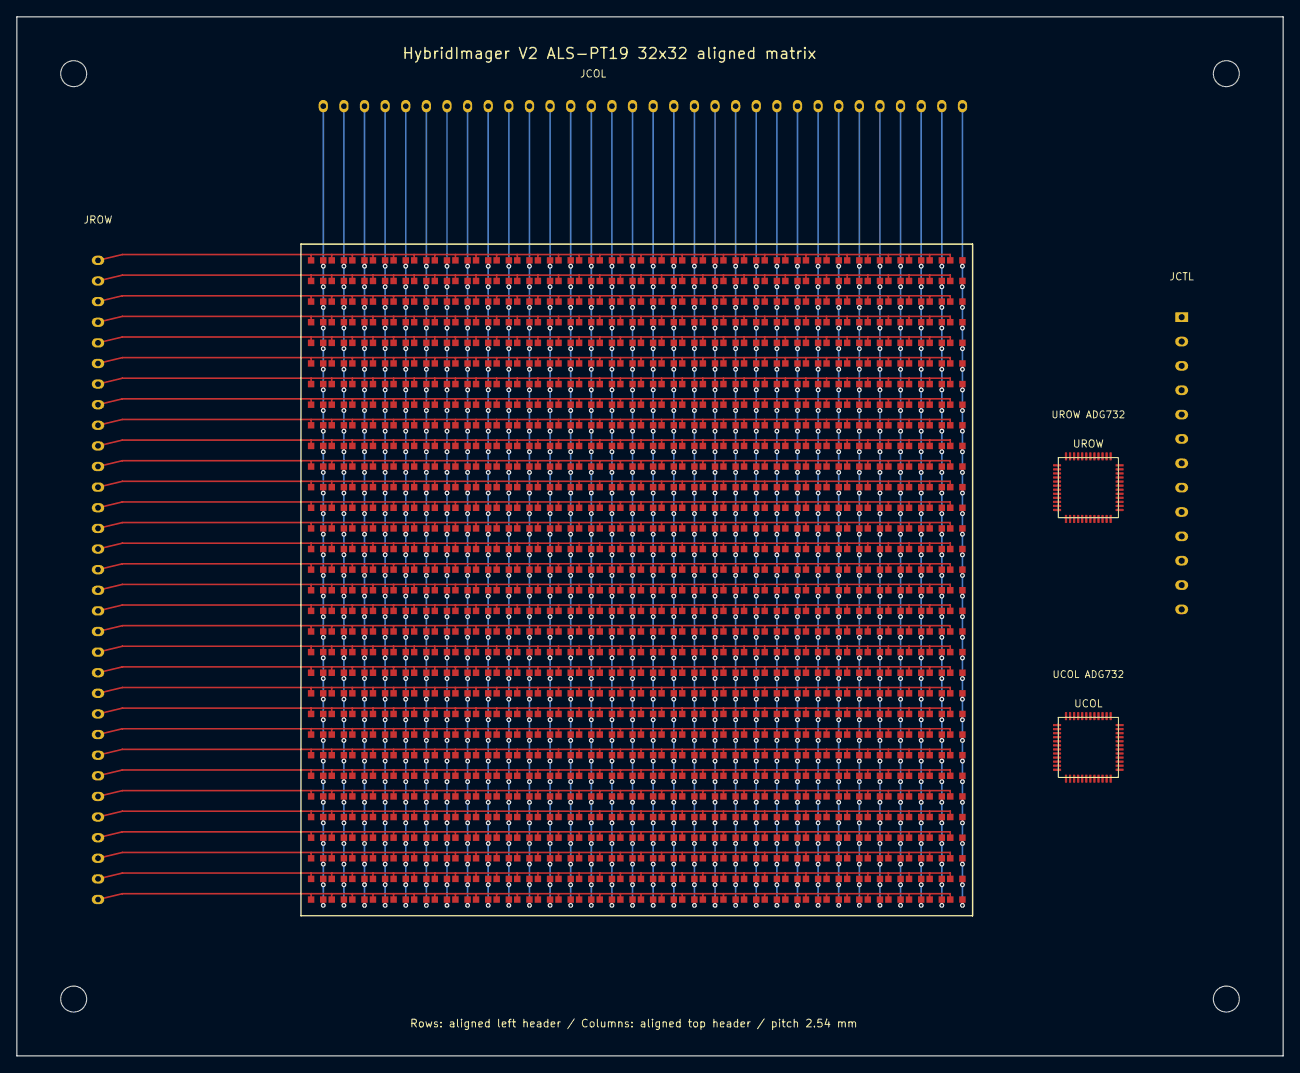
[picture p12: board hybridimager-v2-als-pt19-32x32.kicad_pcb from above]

Board: 2 copper layers, 156.0 x 128.0 mm, 1033 parts (0 on the bottom side), 64 nets.

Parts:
H1, H2, H3, H4: M3; MountingHole_3.2mm_M3
JCOL: COL_EDGE_1x32_ALIGNED; Aligned_Col_Header_1x32_2.54mm
JCTL: ADDR_SYNC_PWR; Control_Header_1x13_3mm
JROW: ROW_EDGE_1x32_ALIGNED; Aligned_Row_Header_1x32_2.54mm
Q0101, Q0102, Q0103, Q0104, Q0105, Q0106, Q0107, Q0108, Q0109, Q0110, Q0111, Q0112, Q0113, Q0114, Q0115, Q0116, Q0117, Q0118, Q0119, Q0120, Q0121, Q0122, Q0123, Q0124, Q0125, Q0126, Q0127, Q0128, Q0129, Q0130, Q0131, Q0132, Q0201, Q0202, Q0203, Q0204, Q0205, Q0206, Q0207, Q0208, Q0209, Q0210, Q0211, Q0212, Q0213, Q0214, Q0215, Q0216, Q0217, Q0218, Q0219, Q0220, Q0221, Q0222, Q0223, Q0224, Q0225, Q0226, Q0227, Q0228, Q0229, Q0230, Q0231, Q0232, Q0301, Q0302, Q0303, Q0304, Q0305, Q0306, Q0307, Q0308, Q0309, Q0310, Q0311, Q0312, Q0313, Q0314, Q0315, Q0316, Q0317, Q0318, Q0319, Q0320, Q0321, Q0322, Q0323, Q0324, Q0325, Q0326, Q0327, Q0328, Q0329, Q0330, Q0331, Q0332, Q0401, Q0402, Q0403, Q0404, Q0405, Q0406, Q0407, Q0408, Q0409, Q0410, Q0411, Q0412, Q0413, Q0414, Q0415, Q0416, Q0417, Q0418, Q0419, Q0420, Q0421, Q0422, Q0423, Q0424, Q0425, Q0426, Q0427, Q0428, Q0429, Q0430, Q0431, Q0432, Q0501, Q0502, Q0503, Q0504, Q0505, Q0506, Q0507, Q0508, Q0509, Q0510, Q0511, Q0512, Q0513, Q0514, Q0515, Q0516, Q0517, Q0518, Q0519, Q0520, Q0521, Q0522, Q0523, Q0524, Q0525, Q0526, Q0527, Q0528, Q0529, Q0530, Q0531, Q0532, Q0601, Q0602, Q0603, Q0604, Q0605, Q0606, Q0607, Q0608, Q0609, Q0610, Q0611, Q0612, Q0613, Q0614, Q0615, Q0616, Q0617, Q0618, Q0619, Q0620, Q0621, Q0622, Q0623, Q0624, Q0625, Q0626, Q0627, Q0628, Q0629, Q0630, Q0631, Q0632, Q0701, Q0702, Q0703, Q0704, Q0705, Q0706, Q0707, Q0708, Q0709, Q0710, Q0711, Q0712, Q0713, Q0714, Q0715, Q0716, Q0717, Q0718, Q0719, Q0720, Q0721, Q0722, Q0723, Q0724, Q0725, Q0726, Q0727, Q0728, Q0729, Q0730, Q0731, Q0732, Q0801, Q0802, Q0803, Q0804, Q0805, Q0806, Q0807, Q0808, Q0809, Q0810, Q0811, Q0812, Q0813, Q0814, Q0815, Q0816, Q0817, Q0818, Q0819, Q0820, Q0821, Q0822, Q0823, Q0824, Q0825, Q0826, Q0827, Q0828, Q0829, Q0830, Q0831, Q0832, Q0901, Q0902, Q0903, Q0904, Q0905, Q0906, Q0907, Q0908, Q0909, Q0910, Q0911, Q0912, Q0913, Q0914, Q0915, Q0916, Q0917, Q0918, Q0919, Q0920, Q0921, Q0922, Q0923, Q0924, Q0925, Q0926, Q0927, Q0928, Q0929, Q0930, Q0931, Q0932, Q1001, Q1002, Q1003, Q1004, Q1005, Q1006, Q1007, Q1008, Q1009, Q1010, Q1011, Q1012, Q1013, Q1014, Q1015, Q1016, Q1017, Q1018, Q1019, Q1020, Q1021, Q1022, Q1023, Q1024, Q1025, Q1026, Q1027, Q1028, Q1029, Q1030, Q1031, Q1032, Q1101, Q1102, Q1103, Q1104, Q1105, Q1106, Q1107, Q1108, Q1109, Q1110, Q1111, Q1112, Q1113, Q1114, Q1115, Q1116, Q1117, Q1118, Q1119, Q1120, Q1121, Q1122, Q1123, Q1124, Q1125, Q1126, Q1127, Q1128, Q1129, Q1130, Q1131, Q1132, Q1201, Q1202, Q1203, Q1204, Q1205, Q1206, Q1207, Q1208, Q1209, Q1210, Q1211, Q1212, Q1213, Q1214, Q1215, Q1216, Q1217, Q1218, Q1219, Q1220, Q1221, Q1222, Q1223, Q1224, Q1225, Q1226, Q1227, Q1228, Q1229, Q1230, Q1231, Q1232, Q1301, Q1302, Q1303, Q1304, Q1305, Q1306, Q1307, Q1308, Q1309, Q1310, Q1311, Q1312, Q1313, Q1314, Q1315, Q1316, Q1317, Q1318, Q1319, Q1320, Q1321, Q1322, Q1323, Q1324, Q1325, Q1326, Q1327, Q1328, Q1329, Q1330, Q1331, Q1332, Q1401, Q1402, Q1403, Q1404, Q1405, Q1406, Q1407, Q1408, Q1409, Q1410, Q1411, Q1412, Q1413, Q1414, Q1415, Q1416, Q1417, Q1418, Q1419, Q1420, Q1421, Q1422, Q1423, Q1424, Q1425, Q1426, Q1427, Q1428, Q1429, Q1430, Q1431, Q1432, Q1501, Q1502, Q1503, Q1504, Q1505, Q1506, Q1507, Q1508, Q1509, Q1510, Q1511, Q1512, Q1513, Q1514, Q1515, Q1516, Q1517, Q1518, Q1519, Q1520, Q1521, Q1522, Q1523, Q1524, Q1525, Q1526, Q1527, Q1528, Q1529, Q1530, Q1531, Q1532, Q1601, Q1602, Q1603, Q1604, Q1605, Q1606, Q1607, Q1608, Q1609, Q1610, Q1611, Q1612, Q1613, Q1614, Q1615, Q1616, Q1617, Q1618, Q1619, Q1620, Q1621, Q1622, Q1623, Q1624, Q1625, Q1626, Q1627, Q1628, Q1629, Q1630, Q1631, Q1632, Q1701, Q1702, Q1703, Q1704, Q1705, Q1706, Q1707, Q1708, Q1709, Q1710, Q1711, Q1712, Q1713, Q1714, Q1715, Q1716, Q1717, Q1718, Q1719, Q1720, Q1721, Q1722, Q1723, Q1724, Q1725, Q1726, Q1727, Q1728, Q1729, Q1730, Q1731, Q1732, Q1801, Q1802, Q1803, Q1804, Q1805, Q1806, Q1807, Q1808, Q1809, Q1810, Q1811, Q1812, Q1813, Q1814, Q1815, Q1816, Q1817, Q1818, Q1819, Q1820, Q1821, Q1822, Q1823, Q1824, Q1825, Q1826, Q1827, Q1828, Q1829, Q1830, Q1831, Q1832, Q1901, Q1902, Q1903, Q1904, Q1905, Q1906, Q1907, Q1908, Q1909, Q1910, Q1911, Q1912, Q1913, Q1914, Q1915, Q1916, Q1917, Q1918, Q1919, Q1920, Q1921, Q1922, Q1923, Q1924, Q1925, Q1926, Q1927, Q1928, Q1929, Q1930, Q1931, Q1932, Q2001, Q2002, Q2003, Q2004, Q2005, Q2006, Q2007, Q2008, Q2009, Q2010, Q2011, Q2012, Q2013, Q2014, Q2015, Q2016, Q2017, Q2018, Q2019, Q2020, Q2021, Q2022, Q2023, Q2024, Q2025, Q2026, Q2027, Q2028, Q2029, Q2030, Q2031, Q2032, Q2101, Q2102, Q2103, Q2104, Q2105, Q2106, Q2107, Q2108, Q2109, Q2110, Q2111, Q2112, Q2113, Q2114, Q2115, Q2116, Q2117, Q2118, Q2119, Q2120, Q2121, Q2122, Q2123, Q2124, Q2125, Q2126, Q2127, Q2128, Q2129, Q2130, Q2131, Q2132, Q2201, Q2202, Q2203, Q2204, Q2205, Q2206, Q2207, Q2208, Q2209, Q2210, Q2211, Q2212, Q2213, Q2214, Q2215, Q2216, Q2217, Q2218, Q2219, Q2220, Q2221, Q2222, Q2223, Q2224, Q2225, Q2226, Q2227, Q2228, Q2229, Q2230, Q2231, Q2232, Q2301, Q2302, Q2303, Q2304, Q2305, Q2306, Q2307, Q2308, Q2309, Q2310, Q2311, Q2312, Q2313, Q2314, Q2315, Q2316, Q2317, Q2318, Q2319, Q2320, Q2321, Q2322, Q2323, Q2324, Q2325, Q2326, Q2327, Q2328, Q2329, Q2330, Q2331, Q2332, Q2401, Q2402, Q2403, Q2404, Q2405, Q2406, Q2407, Q2408, Q2409, Q2410, Q2411, Q2412, Q2413, Q2414, Q2415, Q2416, Q2417, Q2418, Q2419, Q2420, Q2421, Q2422, Q2423, Q2424, Q2425, Q2426, Q2427, Q2428, Q2429, Q2430, Q2431, Q2432, Q2501, Q2502, Q2503, Q2504, Q2505, Q2506, Q2507, Q2508, Q2509, Q2510, Q2511, Q2512, Q2513, Q2514, Q2515, Q2516, Q2517, Q2518, Q2519, Q2520, Q2521, Q2522, Q2523, Q2524, Q2525, Q2526, Q2527, Q2528, Q2529, Q2530, Q2531, Q2532, Q2601, Q2602, Q2603, Q2604, Q2605, Q2606, Q2607, Q2608, Q2609, Q2610, Q2611, Q2612, Q2613, Q2614, Q2615, Q2616, Q2617, Q2618, Q2619, Q2620, Q2621, Q2622, Q2623, Q2624, Q2625, Q2626, Q2627, Q2628, Q2629, Q2630, Q2631, Q2632, Q2701, Q2702, Q2703, Q2704, Q2705, Q2706, Q2707, Q2708, Q2709, Q2710, Q2711, Q2712, Q2713, Q2714, Q2715, Q2716, Q2717, Q2718, Q2719, Q2720, Q2721, Q2722, Q2723, Q2724, Q2725, Q2726, Q2727, Q2728, Q2729, Q2730, Q2731, Q2732, Q2801, Q2802, Q2803, Q2804, Q2805, Q2806, Q2807, Q2808, Q2809, Q2810, Q2811, Q2812, Q2813, Q2814, Q2815, Q2816, Q2817, Q2818, Q2819, Q2820, Q2821, Q2822, Q2823, Q2824, Q2825, Q2826, Q2827, Q2828, Q2829, Q2830, Q2831, Q2832, Q2901, Q2902, Q2903, Q2904, Q2905, Q2906, Q2907, Q2908, Q2909, Q2910, Q2911, Q2912, Q2913, Q2914, Q2915, Q2916, Q2917, Q2918, Q2919, Q2920, Q2921, Q2922, Q2923, Q2924, Q2925, Q2926, Q2927, Q2928, Q2929, Q2930, Q2931, Q2932, Q3001, Q3002, Q3003, Q3004, Q3005, Q3006, Q3007, Q3008, Q3009, Q3010, Q3011, Q3012, Q3013, Q3014, Q3015, Q3016, Q3017, Q3018, Q3019, Q3020, Q3021, Q3022, Q3023, Q3024, Q3025, Q3026, Q3027, Q3028, Q3029, Q3030, Q3031, Q3032, Q3101, Q3102, Q3103, Q3104, Q3105, Q3106, Q3107, Q3108, Q3109, Q3110, Q3111, Q3112, Q3113, Q3114, Q3115, Q3116, Q3117, Q3118, Q3119, Q3120, Q3121, Q3122, Q3123, Q3124, Q3125, Q3126, Q3127, Q3128, Q3129, Q3130, Q3131, Q3132, Q3201, Q3202, Q3203, Q3204, Q3205, Q3206, Q3207, Q3208, Q3209, Q3210, Q3211, Q3212, Q3213, Q3214, Q3215, Q3216, Q3217, Q3218, Q3219, Q3220, Q3221, Q3222, Q3223, Q3224, Q3225, Q3226, Q3227, Q3228, Q3229, Q3230, Q3231, Q3232: ALS-PT19
UCOL: ADG732_32_TO_1_PLACEHOLDER; ADG732_TQFP48_PLACEHOLDER
UROW: ADG732_32_TO_1_PLACEHOLDER; ADG732_TQFP48_PLACEHOLDER

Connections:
COL01: JCOL.1 (COL01), Q0101.2 (COL), Q0201.2 (COL), Q0301.2 (COL), Q0401.2 (COL), Q0501.2 (COL), Q0601.2 (COL), Q0701.2 (COL), Q0801.2 (COL), Q0901.2 (COL), Q1001.2 (COL), Q1101.2 (COL), Q1201.2 (COL), Q1301.2 (COL), Q1401.2 (COL), Q1501.2 (COL), Q1601.2 (COL), Q1701.2 (COL), Q1801.2 (COL), Q1901.2 (COL), Q2001.2 (COL), Q2101.2 (COL), Q2201.2 (COL), Q2301.2 (COL), Q2401.2 (COL), Q2501.2 (COL), Q2601.2 (COL), Q2701.2 (COL), Q2801.2 (COL), Q2901.2 (COL), Q3001.2 (COL), Q3101.2 (COL), Q3201.2 (COL)
COL02: JCOL.2 (COL02), Q0102.2 (COL), Q0202.2 (COL), Q0302.2 (COL), Q0402.2 (COL), Q0502.2 (COL), Q0602.2 (COL), Q0702.2 (COL), Q0802.2 (COL), Q0902.2 (COL), Q1002.2 (COL), Q1102.2 (COL), Q1202.2 (COL), Q1302.2 (COL), Q1402.2 (COL), Q1502.2 (COL), Q1602.2 (COL), Q1702.2 (COL), Q1802.2 (COL), Q1902.2 (COL), Q2002.2 (COL), Q2102.2 (COL), Q2202.2 (COL), Q2302.2 (COL), Q2402.2 (COL), Q2502.2 (COL), Q2602.2 (COL), Q2702.2 (COL), Q2802.2 (COL), Q2902.2 (COL), Q3002.2 (COL), Q3102.2 (COL), Q3202.2 (COL)
COL03: JCOL.3 (COL03), Q0103.2 (COL), Q0203.2 (COL), Q0303.2 (COL), Q0403.2 (COL), Q0503.2 (COL), Q0603.2 (COL), Q0703.2 (COL), Q0803.2 (COL), Q0903.2 (COL), Q1003.2 (COL), Q1103.2 (COL), Q1203.2 (COL), Q1303.2 (COL), Q1403.2 (COL), Q1503.2 (COL), Q1603.2 (COL), Q1703.2 (COL), Q1803.2 (COL), Q1903.2 (COL), Q2003.2 (COL), Q2103.2 (COL), Q2203.2 (COL), Q2303.2 (COL), Q2403.2 (COL), Q2503.2 (COL), Q2603.2 (COL), Q2703.2 (COL), Q2803.2 (COL), Q2903.2 (COL), Q3003.2 (COL), Q3103.2 (COL), Q3203.2 (COL)
COL04: JCOL.4 (COL04), Q0104.2 (COL), Q0204.2 (COL), Q0304.2 (COL), Q0404.2 (COL), Q0504.2 (COL), Q0604.2 (COL), Q0704.2 (COL), Q0804.2 (COL), Q0904.2 (COL), Q1004.2 (COL), Q1104.2 (COL), Q1204.2 (COL), Q1304.2 (COL), Q1404.2 (COL), Q1504.2 (COL), Q1604.2 (COL), Q1704.2 (COL), Q1804.2 (COL), Q1904.2 (COL), Q2004.2 (COL), Q2104.2 (COL), Q2204.2 (COL), Q2304.2 (COL), Q2404.2 (COL), Q2504.2 (COL), Q2604.2 (COL), Q2704.2 (COL), Q2804.2 (COL), Q2904.2 (COL), Q3004.2 (COL), Q3104.2 (COL), Q3204.2 (COL)
COL05: JCOL.5 (COL05), Q0105.2 (COL), Q0205.2 (COL), Q0305.2 (COL), Q0405.2 (COL), Q0505.2 (COL), Q0605.2 (COL), Q0705.2 (COL), Q0805.2 (COL), Q0905.2 (COL), Q1005.2 (COL), Q1105.2 (COL), Q1205.2 (COL), Q1305.2 (COL), Q1405.2 (COL), Q1505.2 (COL), Q1605.2 (COL), Q1705.2 (COL), Q1805.2 (COL), Q1905.2 (COL), Q2005.2 (COL), Q2105.2 (COL), Q2205.2 (COL), Q2305.2 (COL), Q2405.2 (COL), Q2505.2 (COL), Q2605.2 (COL), Q2705.2 (COL), Q2805.2 (COL), Q2905.2 (COL), Q3005.2 (COL), Q3105.2 (COL), Q3205.2 (COL)
COL06: JCOL.6 (COL06), Q0106.2 (COL), Q0206.2 (COL), Q0306.2 (COL), Q0406.2 (COL), Q0506.2 (COL), Q0606.2 (COL), Q0706.2 (COL), Q0806.2 (COL), Q0906.2 (COL), Q1006.2 (COL), Q1106.2 (COL), Q1206.2 (COL), Q1306.2 (COL), Q1406.2 (COL), Q1506.2 (COL), Q1606.2 (COL), Q1706.2 (COL), Q1806.2 (COL), Q1906.2 (COL), Q2006.2 (COL), Q2106.2 (COL), Q2206.2 (COL), Q2306.2 (COL), Q2406.2 (COL), Q2506.2 (COL), Q2606.2 (COL), Q2706.2 (COL), Q2806.2 (COL), Q2906.2 (COL), Q3006.2 (COL), Q3106.2 (COL), Q3206.2 (COL)
COL07: JCOL.7 (COL07), Q0107.2 (COL), Q0207.2 (COL), Q0307.2 (COL), Q0407.2 (COL), Q0507.2 (COL), Q0607.2 (COL), Q0707.2 (COL), Q0807.2 (COL), Q0907.2 (COL), Q1007.2 (COL), Q1107.2 (COL), Q1207.2 (COL), Q1307.2 (COL), Q1407.2 (COL), Q1507.2 (COL), Q1607.2 (COL), Q1707.2 (COL), Q1807.2 (COL), Q1907.2 (COL), Q2007.2 (COL), Q2107.2 (COL), Q2207.2 (COL), Q2307.2 (COL), Q2407.2 (COL), Q2507.2 (COL), Q2607.2 (COL), Q2707.2 (COL), Q2807.2 (COL), Q2907.2 (COL), Q3007.2 (COL), Q3107.2 (COL), Q3207.2 (COL)
COL08: JCOL.8 (COL08), Q0108.2 (COL), Q0208.2 (COL), Q0308.2 (COL), Q0408.2 (COL), Q0508.2 (COL), Q0608.2 (COL), Q0708.2 (COL), Q0808.2 (COL), Q0908.2 (COL), Q1008.2 (COL), Q1108.2 (COL), Q1208.2 (COL), Q1308.2 (COL), Q1408.2 (COL), Q1508.2 (COL), Q1608.2 (COL), Q1708.2 (COL), Q1808.2 (COL), Q1908.2 (COL), Q2008.2 (COL), Q2108.2 (COL), Q2208.2 (COL), Q2308.2 (COL), Q2408.2 (COL), Q2508.2 (COL), Q2608.2 (COL), Q2708.2 (COL), Q2808.2 (COL), Q2908.2 (COL), Q3008.2 (COL), Q3108.2 (COL), Q3208.2 (COL)
COL09: JCOL.9 (COL09), Q0109.2 (COL), Q0209.2 (COL), Q0309.2 (COL), Q0409.2 (COL), Q0509.2 (COL), Q0609.2 (COL), Q0709.2 (COL), Q0809.2 (COL), Q0909.2 (COL), Q1009.2 (COL), Q1109.2 (COL), Q1209.2 (COL), Q1309.2 (COL), Q1409.2 (COL), Q1509.2 (COL), Q1609.2 (COL), Q1709.2 (COL), Q1809.2 (COL), Q1909.2 (COL), Q2009.2 (COL), Q2109.2 (COL), Q2209.2 (COL), Q2309.2 (COL), Q2409.2 (COL), Q2509.2 (COL), Q2609.2 (COL), Q2709.2 (COL), Q2809.2 (COL), Q2909.2 (COL), Q3009.2 (COL), Q3109.2 (COL), Q3209.2 (COL)
COL10: JCOL.10 (COL10), Q0110.2 (COL), Q0210.2 (COL), Q0310.2 (COL), Q0410.2 (COL), Q0510.2 (COL), Q0610.2 (COL), Q0710.2 (COL), Q0810.2 (COL), Q0910.2 (COL), Q1010.2 (COL), Q1110.2 (COL), Q1210.2 (COL), Q1310.2 (COL), Q1410.2 (COL), Q1510.2 (COL), Q1610.2 (COL), Q1710.2 (COL), Q1810.2 (COL), Q1910.2 (COL), Q2010.2 (COL), Q2110.2 (COL), Q2210.2 (COL), Q2310.2 (COL), Q2410.2 (COL), Q2510.2 (COL), Q2610.2 (COL), Q2710.2 (COL), Q2810.2 (COL), Q2910.2 (COL), Q3010.2 (COL), Q3110.2 (COL), Q3210.2 (COL)
COL11: JCOL.11 (COL11), Q0111.2 (COL), Q0211.2 (COL), Q0311.2 (COL), Q0411.2 (COL), Q0511.2 (COL), Q0611.2 (COL), Q0711.2 (COL), Q0811.2 (COL), Q0911.2 (COL), Q1011.2 (COL), Q1111.2 (COL), Q1211.2 (COL), Q1311.2 (COL), Q1411.2 (COL), Q1511.2 (COL), Q1611.2 (COL), Q1711.2 (COL), Q1811.2 (COL), Q1911.2 (COL), Q2011.2 (COL), Q2111.2 (COL), Q2211.2 (COL), Q2311.2 (COL), Q2411.2 (COL), Q2511.2 (COL), Q2611.2 (COL), Q2711.2 (COL), Q2811.2 (COL), Q2911.2 (COL), Q3011.2 (COL), Q3111.2 (COL), Q3211.2 (COL)
COL12: JCOL.12 (COL12), Q0112.2 (COL), Q0212.2 (COL), Q0312.2 (COL), Q0412.2 (COL), Q0512.2 (COL), Q0612.2 (COL), Q0712.2 (COL), Q0812.2 (COL), Q0912.2 (COL), Q1012.2 (COL), Q1112.2 (COL), Q1212.2 (COL), Q1312.2 (COL), Q1412.2 (COL), Q1512.2 (COL), Q1612.2 (COL), Q1712.2 (COL), Q1812.2 (COL), Q1912.2 (COL), Q2012.2 (COL), Q2112.2 (COL), Q2212.2 (COL), Q2312.2 (COL), Q2412.2 (COL), Q2512.2 (COL), Q2612.2 (COL), Q2712.2 (COL), Q2812.2 (COL), Q2912.2 (COL), Q3012.2 (COL), Q3112.2 (COL), Q3212.2 (COL)
COL13: JCOL.13 (COL13), Q0113.2 (COL), Q0213.2 (COL), Q0313.2 (COL), Q0413.2 (COL), Q0513.2 (COL), Q0613.2 (COL), Q0713.2 (COL), Q0813.2 (COL), Q0913.2 (COL), Q1013.2 (COL), Q1113.2 (COL), Q1213.2 (COL), Q1313.2 (COL), Q1413.2 (COL), Q1513.2 (COL), Q1613.2 (COL), Q1713.2 (COL), Q1813.2 (COL), Q1913.2 (COL), Q2013.2 (COL), Q2113.2 (COL), Q2213.2 (COL), Q2313.2 (COL), Q2413.2 (COL), Q2513.2 (COL), Q2613.2 (COL), Q2713.2 (COL), Q2813.2 (COL), Q2913.2 (COL), Q3013.2 (COL), Q3113.2 (COL), Q3213.2 (COL)
COL14: JCOL.14 (COL14), Q0114.2 (COL), Q0214.2 (COL), Q0314.2 (COL), Q0414.2 (COL), Q0514.2 (COL), Q0614.2 (COL), Q0714.2 (COL), Q0814.2 (COL), Q0914.2 (COL), Q1014.2 (COL), Q1114.2 (COL), Q1214.2 (COL), Q1314.2 (COL), Q1414.2 (COL), Q1514.2 (COL), Q1614.2 (COL), Q1714.2 (COL), Q1814.2 (COL), Q1914.2 (COL), Q2014.2 (COL), Q2114.2 (COL), Q2214.2 (COL), Q2314.2 (COL), Q2414.2 (COL), Q2514.2 (COL), Q2614.2 (COL), Q2714.2 (COL), Q2814.2 (COL), Q2914.2 (COL), Q3014.2 (COL), Q3114.2 (COL), Q3214.2 (COL)
COL15: JCOL.15 (COL15), Q0115.2 (COL), Q0215.2 (COL), Q0315.2 (COL), Q0415.2 (COL), Q0515.2 (COL), Q0615.2 (COL), Q0715.2 (COL), Q0815.2 (COL), Q0915.2 (COL), Q1015.2 (COL), Q1115.2 (COL), Q1215.2 (COL), Q1315.2 (COL), Q1415.2 (COL), Q1515.2 (COL), Q1615.2 (COL), Q1715.2 (COL), Q1815.2 (COL), Q1915.2 (COL), Q2015.2 (COL), Q2115.2 (COL), Q2215.2 (COL), Q2315.2 (COL), Q2415.2 (COL), Q2515.2 (COL), Q2615.2 (COL), Q2715.2 (COL), Q2815.2 (COL), Q2915.2 (COL), Q3015.2 (COL), Q3115.2 (COL), Q3215.2 (COL)
COL16: JCOL.16 (COL16), Q0116.2 (COL), Q0216.2 (COL), Q0316.2 (COL), Q0416.2 (COL), Q0516.2 (COL), Q0616.2 (COL), Q0716.2 (COL), Q0816.2 (COL), Q0916.2 (COL), Q1016.2 (COL), Q1116.2 (COL), Q1216.2 (COL), Q1316.2 (COL), Q1416.2 (COL), Q1516.2 (COL), Q1616.2 (COL), Q1716.2 (COL), Q1816.2 (COL), Q1916.2 (COL), Q2016.2 (COL), Q2116.2 (COL), Q2216.2 (COL), Q2316.2 (COL), Q2416.2 (COL), Q2516.2 (COL), Q2616.2 (COL), Q2716.2 (COL), Q2816.2 (COL), Q2916.2 (COL), Q3016.2 (COL), Q3116.2 (COL), Q3216.2 (COL)
COL17: JCOL.17 (COL17), Q0117.2 (COL), Q0217.2 (COL), Q0317.2 (COL), Q0417.2 (COL), Q0517.2 (COL), Q0617.2 (COL), Q0717.2 (COL), Q0817.2 (COL), Q0917.2 (COL), Q1017.2 (COL), Q1117.2 (COL), Q1217.2 (COL), Q1317.2 (COL), Q1417.2 (COL), Q1517.2 (COL), Q1617.2 (COL), Q1717.2 (COL), Q1817.2 (COL), Q1917.2 (COL), Q2017.2 (COL), Q2117.2 (COL), Q2217.2 (COL), Q2317.2 (COL), Q2417.2 (COL), Q2517.2 (COL), Q2617.2 (COL), Q2717.2 (COL), Q2817.2 (COL), Q2917.2 (COL), Q3017.2 (COL), Q3117.2 (COL), Q3217.2 (COL)
COL18: JCOL.18 (COL18), Q0118.2 (COL), Q0218.2 (COL), Q0318.2 (COL), Q0418.2 (COL), Q0518.2 (COL), Q0618.2 (COL), Q0718.2 (COL), Q0818.2 (COL), Q0918.2 (COL), Q1018.2 (COL), Q1118.2 (COL), Q1218.2 (COL), Q1318.2 (COL), Q1418.2 (COL), Q1518.2 (COL), Q1618.2 (COL), Q1718.2 (COL), Q1818.2 (COL), Q1918.2 (COL), Q2018.2 (COL), Q2118.2 (COL), Q2218.2 (COL), Q2318.2 (COL), Q2418.2 (COL), Q2518.2 (COL), Q2618.2 (COL), Q2718.2 (COL), Q2818.2 (COL), Q2918.2 (COL), Q3018.2 (COL), Q3118.2 (COL), Q3218.2 (COL)
COL19: JCOL.19 (COL19), Q0119.2 (COL), Q0219.2 (COL), Q0319.2 (COL), Q0419.2 (COL), Q0519.2 (COL), Q0619.2 (COL), Q0719.2 (COL), Q0819.2 (COL), Q0919.2 (COL), Q1019.2 (COL), Q1119.2 (COL), Q1219.2 (COL), Q1319.2 (COL), Q1419.2 (COL), Q1519.2 (COL), Q1619.2 (COL), Q1719.2 (COL), Q1819.2 (COL), Q1919.2 (COL), Q2019.2 (COL), Q2119.2 (COL), Q2219.2 (COL), Q2319.2 (COL), Q2419.2 (COL), Q2519.2 (COL), Q2619.2 (COL), Q2719.2 (COL), Q2819.2 (COL), Q2919.2 (COL), Q3019.2 (COL), Q3119.2 (COL), Q3219.2 (COL)
COL20: JCOL.20 (COL20), Q0120.2 (COL), Q0220.2 (COL), Q0320.2 (COL), Q0420.2 (COL), Q0520.2 (COL), Q0620.2 (COL), Q0720.2 (COL), Q0820.2 (COL), Q0920.2 (COL), Q1020.2 (COL), Q1120.2 (COL), Q1220.2 (COL), Q1320.2 (COL), Q1420.2 (COL), Q1520.2 (COL), Q1620.2 (COL), Q1720.2 (COL), Q1820.2 (COL), Q1920.2 (COL), Q2020.2 (COL), Q2120.2 (COL), Q2220.2 (COL), Q2320.2 (COL), Q2420.2 (COL), Q2520.2 (COL), Q2620.2 (COL), Q2720.2 (COL), Q2820.2 (COL), Q2920.2 (COL), Q3020.2 (COL), Q3120.2 (COL), Q3220.2 (COL)
COL21: JCOL.21 (COL21), Q0121.2 (COL), Q0221.2 (COL), Q0321.2 (COL), Q0421.2 (COL), Q0521.2 (COL), Q0621.2 (COL), Q0721.2 (COL), Q0821.2 (COL), Q0921.2 (COL), Q1021.2 (COL), Q1121.2 (COL), Q1221.2 (COL), Q1321.2 (COL), Q1421.2 (COL), Q1521.2 (COL), Q1621.2 (COL), Q1721.2 (COL), Q1821.2 (COL), Q1921.2 (COL), Q2021.2 (COL), Q2121.2 (COL), Q2221.2 (COL), Q2321.2 (COL), Q2421.2 (COL), Q2521.2 (COL), Q2621.2 (COL), Q2721.2 (COL), Q2821.2 (COL), Q2921.2 (COL), Q3021.2 (COL), Q3121.2 (COL), Q3221.2 (COL)
COL22: JCOL.22 (COL22), Q0122.2 (COL), Q0222.2 (COL), Q0322.2 (COL), Q0422.2 (COL), Q0522.2 (COL), Q0622.2 (COL), Q0722.2 (COL), Q0822.2 (COL), Q0922.2 (COL), Q1022.2 (COL), Q1122.2 (COL), Q1222.2 (COL), Q1322.2 (COL), Q1422.2 (COL), Q1522.2 (COL), Q1622.2 (COL), Q1722.2 (COL), Q1822.2 (COL), Q1922.2 (COL), Q2022.2 (COL), Q2122.2 (COL), Q2222.2 (COL), Q2322.2 (COL), Q2422.2 (COL), Q2522.2 (COL), Q2622.2 (COL), Q2722.2 (COL), Q2822.2 (COL), Q2922.2 (COL), Q3022.2 (COL), Q3122.2 (COL), Q3222.2 (COL)
COL23: JCOL.23 (COL23), Q0123.2 (COL), Q0223.2 (COL), Q0323.2 (COL), Q0423.2 (COL), Q0523.2 (COL), Q0623.2 (COL), Q0723.2 (COL), Q0823.2 (COL), Q0923.2 (COL), Q1023.2 (COL), Q1123.2 (COL), Q1223.2 (COL), Q1323.2 (COL), Q1423.2 (COL), Q1523.2 (COL), Q1623.2 (COL), Q1723.2 (COL), Q1823.2 (COL), Q1923.2 (COL), Q2023.2 (COL), Q2123.2 (COL), Q2223.2 (COL), Q2323.2 (COL), Q2423.2 (COL), Q2523.2 (COL), Q2623.2 (COL), Q2723.2 (COL), Q2823.2 (COL), Q2923.2 (COL), Q3023.2 (COL), Q3123.2 (COL), Q3223.2 (COL)
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

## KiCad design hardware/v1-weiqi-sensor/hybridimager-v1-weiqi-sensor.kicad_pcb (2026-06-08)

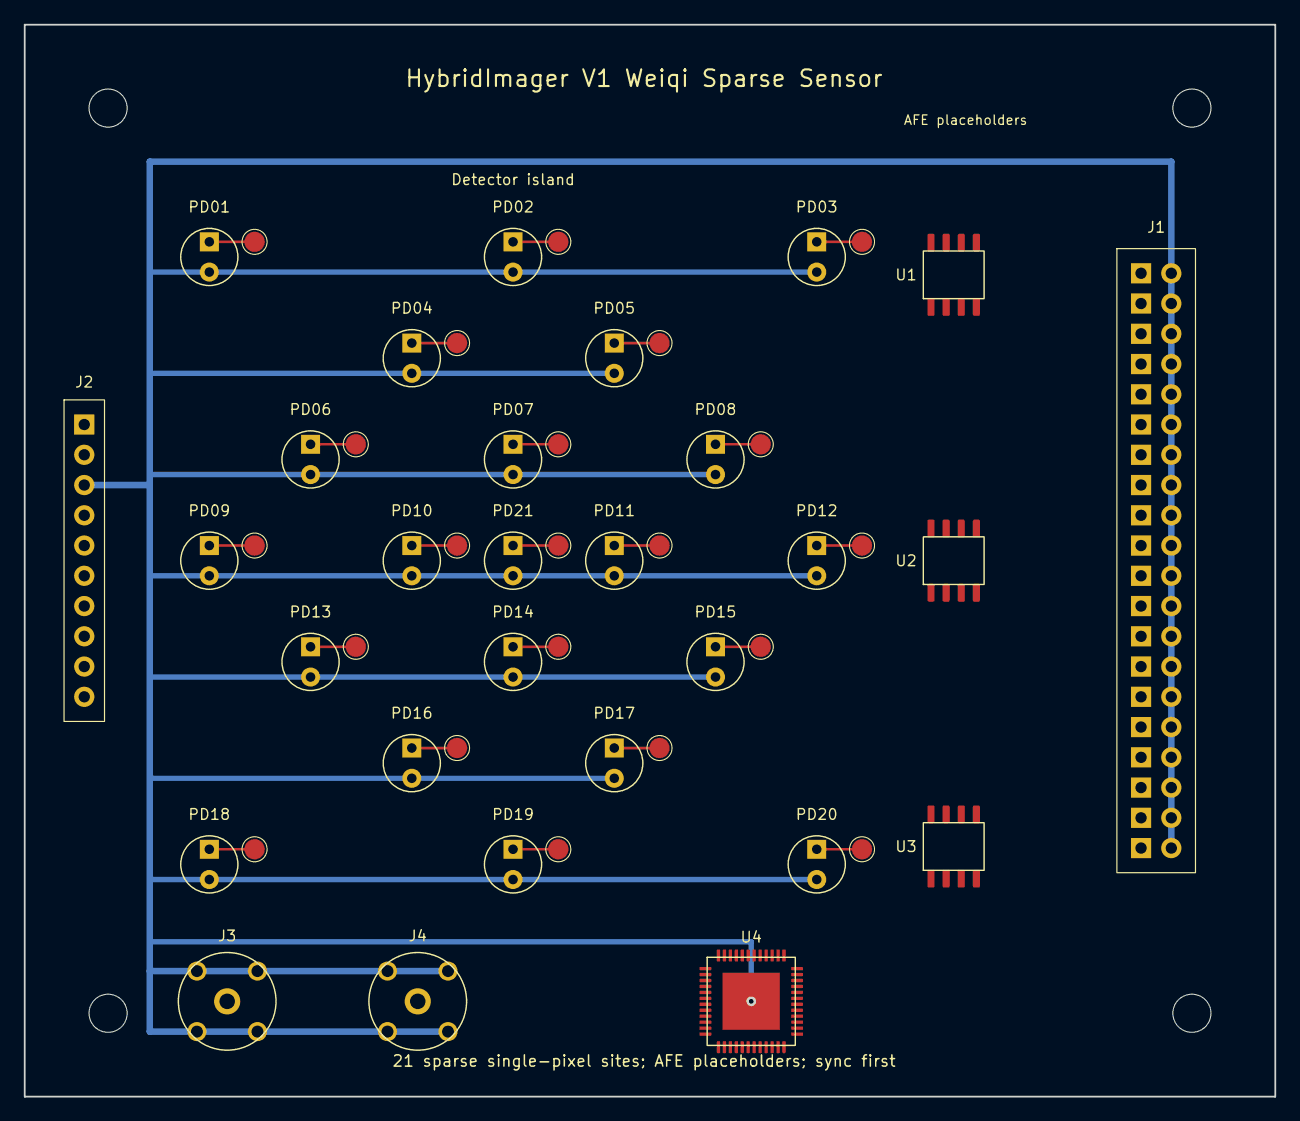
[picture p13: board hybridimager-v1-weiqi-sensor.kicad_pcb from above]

Board: 2 copper layers, 105.0 x 90.0 mm, 54 parts (0 on the bottom side), 22 nets.

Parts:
H1, H2, H3, H4: M3; MountingHole_3.2mm_M3
J1: AFE_EXPANSION_2x20; PinHeader_2x20_P2.54mm_Vertical
J2: SYNC_PWR_1x10; PinHeader_1x10_P2.54mm_Vertical
J3: SYNC_IN; SMA_Amphenol_132291_Vertical
J4: SYNC_OUT; SMA_Amphenol_132291_Vertical
PD01, PD02, PD03, PD04, PD05, PD06, PD07, PD08, PD09, PD10, PD11, PD12, PD13, PD14, PD15, PD16, PD17, PD18, PD19, PD20, PD21: SPARSE_PHOTODIODE_D3; Sparse_SP_D3_Photodiode
TP01: SP01; TP_1.7mm_SMD
TP02: SP02; TP_1.7mm_SMD
TP03: SP03; TP_1.7mm_SMD
TP04: SP04; TP_1.7mm_SMD
TP05: SP05; TP_1.7mm_SMD
TP06: SP06; TP_1.7mm_SMD
TP07: SP07; TP_1.7mm_SMD
TP08: SP08; TP_1.7mm_SMD
TP09: SP09; TP_1.7mm_SMD
TP10: SP10; TP_1.7mm_SMD
TP11: SP11; TP_1.7mm_SMD
TP12: SP12; TP_1.7mm_SMD
TP13: SP13; TP_1.7mm_SMD
TP14: SP14; TP_1.7mm_SMD
TP15: SP15; TP_1.7mm_SMD
TP16: SP16; TP_1.7mm_SMD
TP17: SP17; TP_1.7mm_SMD
TP18: SP18; TP_1.7mm_SMD
TP19: SP19; TP_1.7mm_SMD
TP20: SP20; TP_1.7mm_SMD
TP21: SP21; TP_1.7mm_SMD
U1, U2, U3: TIA_PLACEHOLDER; SOIC-8_3.9x4.9mm_P1.27mm
U4: TIMESTAMP_MCU_FPGA_PLACEHOLDER; QFN-48-1EP_7x7mm_P0.5mm_EP5.15x5.15mm

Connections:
GND: J1.2 (GND), J1.4 (GND), J1.6 (GND), J1.8 (GND), J1.10 (GND), J1.12 (GND), J1.14 (GND), J1.16 (GND), J1.18 (GND), J1.20 (GND), J1.22 (GND), J1.24 (GND), J1.26 (GND), J1.28 (GND), J1.30 (GND), J1.32 (GND), J1.34 (GND), J1.36 (GND), J1.38 (GND), J1.40 (GND), J2.3 (GND), J3.2 (GND), J3.3 (GND), J3.4 (GND), J3.5 (GND), J4.2 (GND), J4.3 (GND), J4.4 (GND), J4.5 (GND), PD01.G (GUARD), PD02.G (GUARD), PD03.G (GUARD), PD04.G (GUARD), PD05.G (GUARD), PD06.G (GUARD), PD07.G (GUARD), PD08.G (GUARD), PD09.G (GUARD), PD10.G (GUARD), PD11.G (GUARD), PD12.G (GUARD), PD13.G (GUARD), PD14.G (GUARD), PD15.G (GUARD), PD16.G (GUARD), PD17.G (GUARD), PD18.G (GUARD), PD19.G (GUARD), PD20.G (GUARD), PD21.G (GUARD), U4.EP
SP01: PD01.S (SIGNAL), TP01.1 (PROBE)
SP02: PD02.S (SIGNAL), TP02.1 (PROBE)
SP03: PD03.S (SIGNAL), TP03.1 (PROBE)
SP04: PD04.S (SIGNAL), TP04.1 (PROBE)
SP05: PD05.S (SIGNAL), TP05.1 (PROBE)
SP06: PD06.S (SIGNAL), TP06.1 (PROBE)
SP07: PD07.S (SIGNAL), TP07.1 (PROBE)
SP08: PD08.S (SIGNAL), TP08.1 (PROBE)
SP09: PD09.S (SIGNAL), TP09.1 (PROBE)
SP10: PD10.S (SIGNAL), TP10.1 (PROBE)
SP11: PD11.S (SIGNAL), TP11.1 (PROBE)
SP12: PD12.S (SIGNAL), TP12.1 (PROBE)
SP13: PD13.S (SIGNAL), TP13.1 (PROBE)
SP14: PD14.S (SIGNAL), TP14.1 (PROBE)
SP15: PD15.S (SIGNAL), TP15.1 (PROBE)
SP16: PD16.S (SIGNAL), TP16.1 (PROBE)
SP17: PD17.S (SIGNAL), TP17.1 (PROBE)
SP18: PD18.S (SIGNAL), TP18.1 (PROBE)
SP19: PD19.S (SIGNAL), TP19.1 (PROBE)
SP20: PD20.S (SIGNAL), TP20.1 (PROBE)
SP21: PD21.S (SIGNAL), TP21.1 (PROBE)

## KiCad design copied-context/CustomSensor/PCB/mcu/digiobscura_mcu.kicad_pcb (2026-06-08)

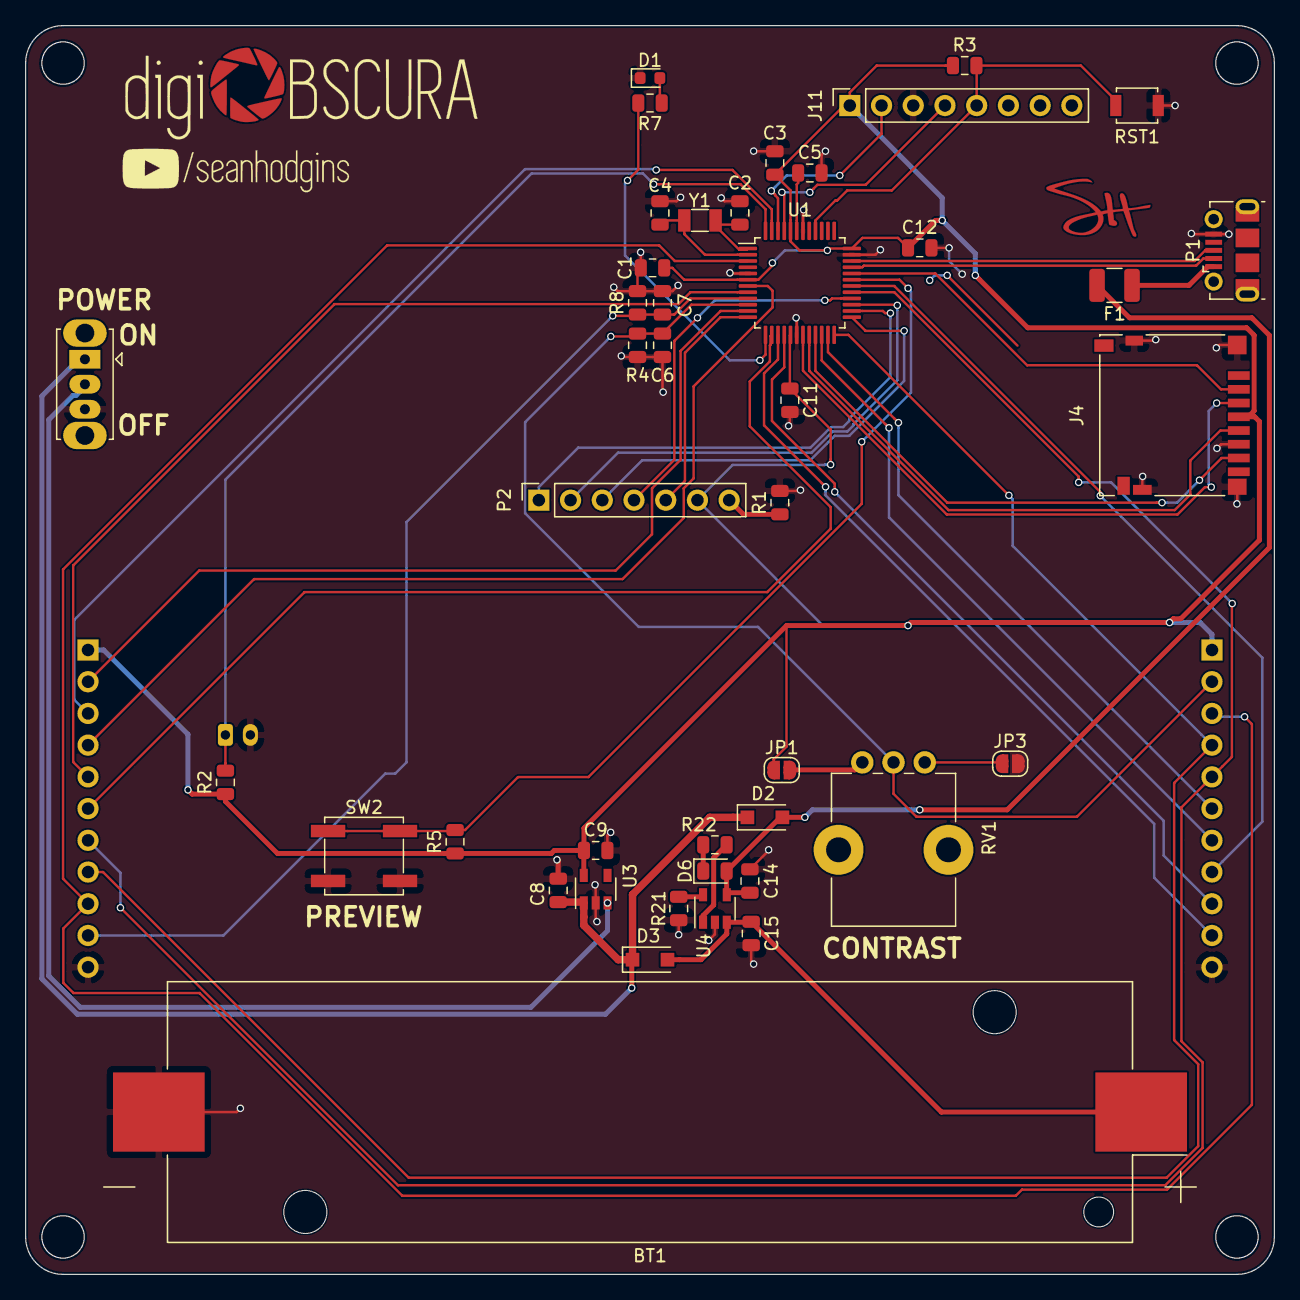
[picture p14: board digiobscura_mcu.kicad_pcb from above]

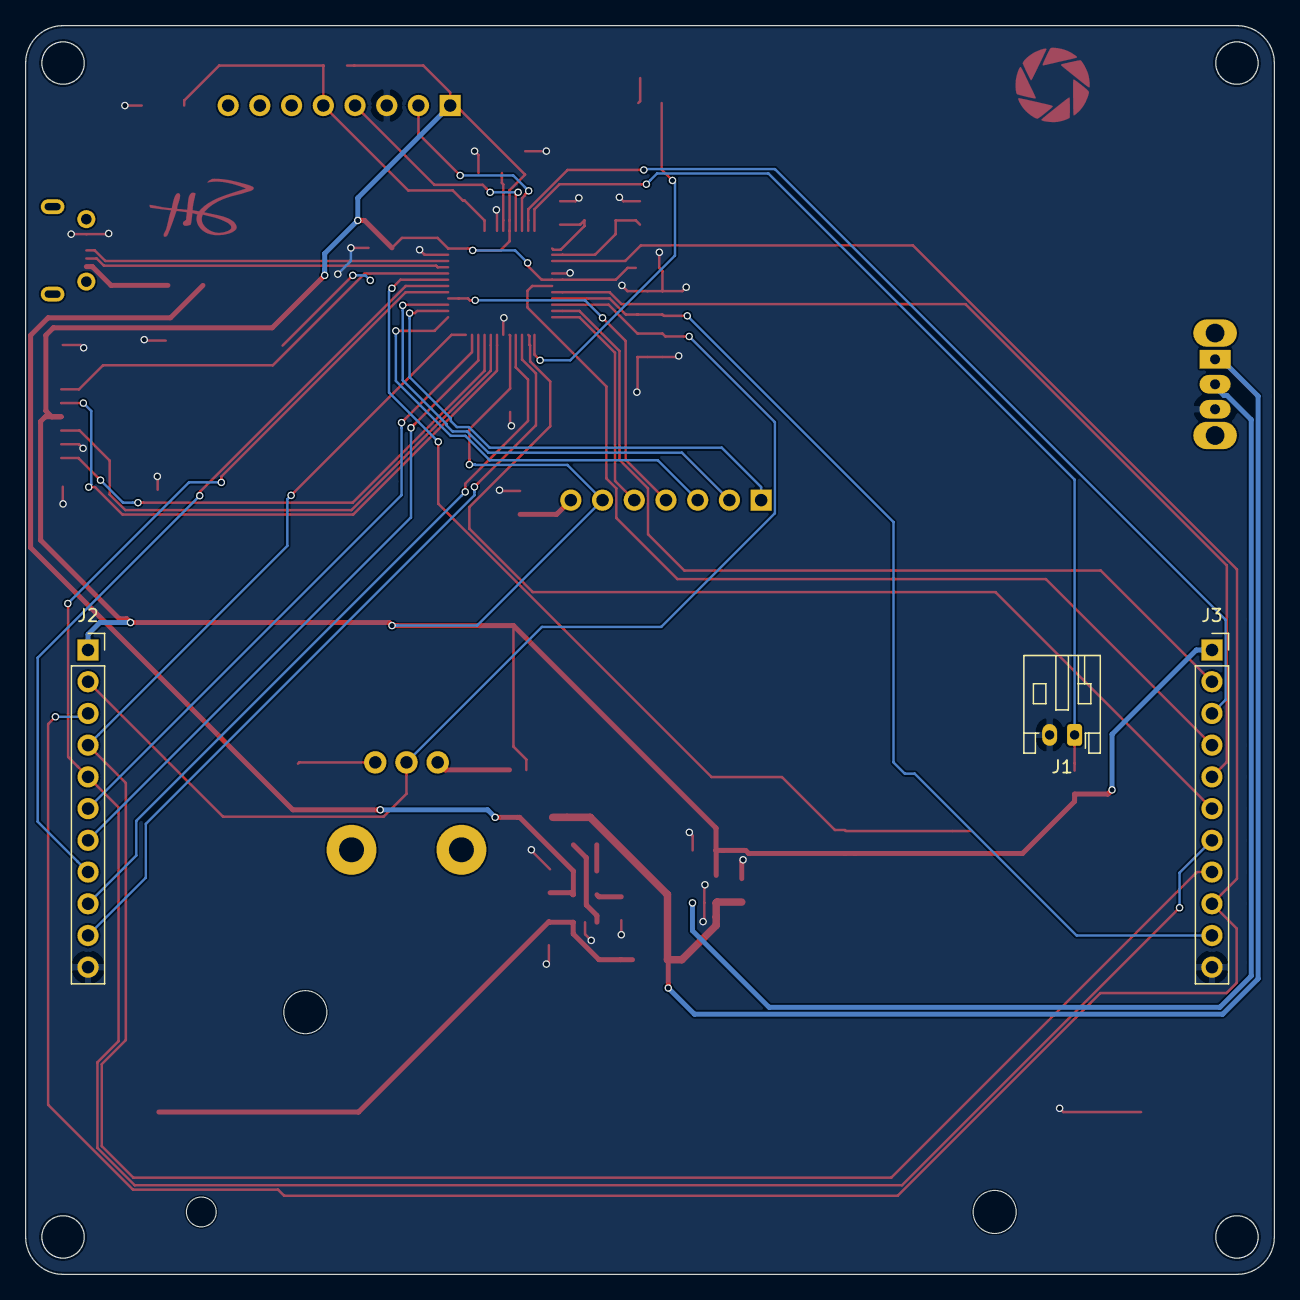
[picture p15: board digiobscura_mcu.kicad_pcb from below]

Board: 2 copper layers, 100.0 x 100.0 mm, 45 parts (3 on the bottom side), 49 nets.

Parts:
BT1: BATT1; BatteryHolder_Keystone_1042_1x18650
C1, C3, C5, C11, C12: 0.1uF; C_0805_2012Metric
C2, C4: 22pF; C_0805_2012Metric
C6, C7, C8: 1uF; C_0805_2012Metric
C9: 2.2uF; C_0805_2012Metric
C14, C15: 4.7uF; C_0805_2012Metric
D1: LED_Small; LED_0603_1608Metric
D2, D3: MBR230L; D_SOD-123F
D6: CHRG; LED_0805_2012Metric
F1: 500mA; Fuse_1210_3225Metric
J1: Conn_01x02; JST_PH_S2B-PH-K_1x02_P2.00mm_Horizontal
J2: ROW; PinSocket_1x11_P2.54mm_Vertical
J3: COL; PinSocket_1x11_P2.54mm_Vertical
J4: Micro_SD_Card_Det; microSD_HC_Hirose_DM3D-SF
J11: Conn_01x08; PinSocket_1x08_P2.54mm_Vertical
JP1: jmp2; SolderJumper-2_P1.3mm_Open_RoundedPad1.0x1.5mm
JP3: jmp3; SolderJumper-2_P1.3mm_Open_RoundedPad1.0x1.5mm
P1: USB_OTG; USB_Micro-B_Molex-105017-0001
P2: CONN_01X07; PinSocket_1x07_P2.54mm_Vertical
R1: 100k; R_0805_2012Metric
R2, R4, R8: 4.7K; R_0805_2012Metric
R3: 10k; R_0805_2012Metric
R5: 10K; R_0805_2012Metric
R7: 1k; R_0805_2012Metric
R21: 6.8k; R_0805_2012Metric
R22: 1K; R_0805_2012Metric
RST1: SW_PUSH; SW_SPST_B3U-1000P
RV1: R_POT; Potentiometer_Bourns_PTV09A-1_Single_Vertical
SW1: SW_Push_SPDT; SW_Slide_1P2T_CK_OS102011MS2Q
SW2: SW_Push; SW_SPST_EVPBF
U1: SAMD21G18A_ArduinoSimple; LQFP-48_7x7mm_P0.5mm
U3: SPX3819-3.3V; SOT-23-5
U4: MCP73812T; SOT-23-5
Y1: Crystal_Small; Crystal_SMD_3215-2Pin_3.2x1.5mm

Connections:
+3V3: C1.1, C3.1, C9.1, C11.1, C12.1, J2.1, J3.1, J4.4, J11.1, JP1.1, P2.6, R2.1, R3.1, R5.1, U1.6, U1.17, U1.36, U1.44, U3.5
A0COL: J3.2, U1.11
A0ROW: J2.10, U1.15
A1COL: J3.3, U1.47
A1ROW: J2.9, U1.16
A2COL: J3.4, U1.7
A2ROW: J2.8, U1.30
A3COL: J3.5, U1.8
A3ROW: J2.7, U1.22
A4COL: J3.6, U1.14
A4ROW: J2.6, U1.23
BUTTON1: J1.1, R2.2, U1.48
BUTTON2: R5.2, SW2.1, U1.31
CLK: P2.5, U1.12
CS: J2.5, J3.7, U1.29
CS_oled: P2.1, U1.26
DATA: P2.4, U1.28
DC: P2.2, U1.27
EN: J2.3, J3.9, U1.3
GND: BT1.2, C1.2, C2.2, C3.2, C4.2, C5.2, C6.2, C7.2, C8.2, C9.2, C11.2, C12.2, C14.2, C15.2, D1.1, J1.2, J2.11, J3.11, J4.6, J4.11, J11.3, JP3.2, P1.5, R1.2, R4.2, R8.2, R21.1, RST1.1, SW1.3, SW2.2, U1.5, U1.18, U1.35, U1.42, U3.2, U4.2
LED1: R7.2, U1.13
unnamed: C2.1, U1.1, Y1.2
unnamed: C4.1, U1.2, Y1.1
unnamed: C5.1, U1.43
unnamed: D1.2, R7.1
unnamed: D6.1, R22.2
unnamed: F1.1, P1.1
unnamed: JP1.2, RV1.1
unnamed: JP3.1, RV1.3
unnamed: P2.7, R1.1
unnamed: R21.2, U4.5
ON: C8.1, D2.1, D3.1, SW1.1, U3.1
OUTCOL: C7.1, J3.10, R8.1, U1.9
OUTROW: C6.1, J2.2, R4.1, RV1.2, U1.10
PEN: SW1.2, U3.3
RES: P2.3, U1.25
RESET: J11.5, R3.2, RST1.2, U1.40
SD_CS: J4.2, U1.32
SD_MISO: J4.7, U1.21
SD_MOSI: J4.3, U1.19
SD_SCK: J4.5, U1.20
SWCLK: J11.4, U1.45
SWDIO: J11.2, U1.46
USB_D+: P1.3, U1.34
USB_D-: P1.2, U1.33
VBATT: BT1.1, C15.1, D3.2, U4.3
VCOM: C14.1, D2.2, D6.2, F1.2, U4.4
WR: J2.4, J3.8, U1.24
st: R22.1, U4.1

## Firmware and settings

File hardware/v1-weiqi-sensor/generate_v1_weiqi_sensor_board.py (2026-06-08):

#!/usr/bin/env python3
"""Generate the HybridImager V1 sparse Weiqi sensor-board draft."""

from __future__ import annotations

import csv
import json
import math
import shutil
import uuid
from pathlib import Path

import matplotlib.pyplot as plt
import numpy as np
from mpl_toolkits.mplot3d.art3d import Poly3DCollection


ROOT = Path(__file__).resolve().parents[1]
OUT_DIR = ROOT / "hardware/v1-weiqi-sensor"
ARTIFACT_DIR = OUT_DIR / "artifacts"
GERBER_DIR = OUT_DIR / "gerber"
BOARD_NAME = "hybridimager-v1-weiqi-sensor"
BOARD = OUT_DIR / f"{BOARD_NAME}.kicad_pcb"
PROJECT = OUT_DIR / f"{BOARD_NAME}.kicad_pro"
SCHEMATIC = OUT_DIR / f"{BOARD_NAME}.kicad_sch"
FP_LIB_TABLE = OUT_DIR / "fp-lib-table"
DATASET = OUT_DIR / "hybridimager-v1-source-dataset.json"
BOM = OUT_DIR / "hybridimager-v1-bom.csv"
README = OUT_DIR / "README.md"
LOCAL_GITIGNORE = OUT_DIR / ".gitignore"
PREVIEW = ARTIFACT_DIR / "hybridimager-v1-full-view-render.png"

MODEL_LED = "/usr/share/kicad/3dmodels/LED_THT.3dshapes/LED_D3.0mm_IRBlack.step"
MODEL_SOIC = "/usr/share/kicad/3dmodels/Package_SO.3dshapes/SOIC-8_3.9x4.9mm_P1.27mm.step"
MODEL_QFN = "/usr/share/kicad/3dmodels/Package_DFN_QFN.3dshapes/QFN-48-1EP_7x7mm_P0.5mm_EP5.15x5.15mm.step"
MODEL_2X20 = "/usr/share/kicad/3dmodels/Connector_PinHeader_2.54mm.3dshapes/PinHeader_2x20_P2.54mm_Vertical.step"
MODEL_1X10 = "/usr/share/kicad/3dmodels/Connector_PinHeader_2.54mm.3dshapes/PinHeader_1x10_P2.54mm_Vertical.step"
MODEL_SMA = "/usr/share/kicad/3dmodels/Connector_Coaxial.3dshapes/SMA_Amphenol_132291_Vertical.step"


def uid(name: str) -> str:
    return str(uuid.uuid5(uuid.NAMESPACE_URL, f"lazyingart:hybridimager:{BOARD_NAME}:{name}"))


def prop(name: str, value: str, at: str, layer: str = "F.Fab", hide: bool = False) -> str:
    hidden = "\n\t\t\t(hide yes)" if hide else ""
    return f"""\t\t(property "{name}" "{value}"
\t\t\t(at {at})
\t\t\t(layer "{layer}"){hidden}
\t\t\t(uuid "{uid(f'prop:{name}:{value}:{at}:{layer}')}")
\t\t\t(effects (font (size 0.9 0.9) (thickness 0.12)))
\t\t)"""


def gr_line(layer: str, x1: float, y1: float, x2: float, y2: float, name: str, width: float = 0.12) -> str:
    return f'\t(gr_line (start {x1:g} {y1:g}) (end {x2:g} {y2:g}) (stroke (width {width:g}) (type solid)) (layer "{layer}") (uuid "{uid(name)}"))'


def gr_rect(layer: str, x1: float, y1: float, x2: float, y2: float, name: str, width: float = 0.12) -> str:
    return "\n".join(
        [
            gr_line(layer, x1, y1, x2, y1, f"{name}:top", width),
            gr_line(layer, x2, y1, x2, y2, f"{name}:right", width),
            gr_line(layer, x2, y2, x1, y2, f"{name}:bottom", width),
            gr_line(layer, x1, y2, x1, y1, f"{name}:left", width),
        ]
    )


def track(name: str, layer: str, x1: float, y1: float, x2: float, y2: float, net_id: int = 1, width: float = 0.45) -> str:
    return f'\t(segment (start {x1:g} {y1:g}) (end {x2:g} {y2:g}) (width {width:g}) (layer "{layer}") (net {net_id}) (uuid "{uid(name)}"))'


def via(name: str, x: float, y: float, net_id: int = 1) -> str:
    return f'\t(via (at {x:g} {y:g}) (size 0.8) (drill 0.4) (layers "F.Cu" "B.Cu") (net {net_id}) (uuid "{uid(name)}"))'


def mounting_hole(ref: str, x: float, y: float) -> str:
    return f"""
\t(footprint "MountingHole:MountingHole_3.2mm_M3"
\t\t(layer "F.Cu")
\t\t(uuid "{uid(ref)}")
\t\t(at {x:g} {y:g})
{prop("Reference", ref, "0 -4 0", "F.Fab", True)}
{prop("Value", "M3", "0 4 0", "F.Fab", True)}
\t\t(attr exclude_from_pos_files)
\t\t(fp_circle (center 0 0) (end 3.2 0) (stroke (width 0.15) (type solid)) (fill none) (layer "Cmts.User") (uuid "{uid(ref + ':circle')}"))
\t\t(pad "" np_thru_hole circle (at 0 0) (size 3.2 3.2) (drill 3.2) (layers "*.Cu" "*.Mask") (uuid "{uid(ref + ':pad')}"))
\t)"""


def detector(ref: str, x: float, y: float, net_id: int, net_name: str) -> str:
    return f"""
\t(footprint "Sparse_SP_D3_Photodiode"
\t\t(layer "F.Cu")
\t\t(uuid "{uid(ref)}")
\t\t(at {x:g} {y:g})
\t\t(descr "V1 sparse single-pixel detector placeholder, 3 mm THT photodiode class")
\t\t(tags "single-pixel sparse photodiode weiqi")
{prop("Reference", ref, "0 -4.2 0", "F.SilkS")}
{prop("Value", "SPARSE_PHOTODIODE_D3", "0 4.2 0", "F.Fab", True)}
\t\t(attr through_hole)
\t\t(fp_circle (center 0 0) (end 2.4 0) (stroke (width 0.12) (type solid)) (fill none) (layer "F.SilkS") (uuid "{uid(ref + ':silk')}"))
\t\t(fp_circle (center 0 0) (end 3.1 0) (stroke (width 0.05) (type solid)) (fill none) (layer "F.CrtYd") (uuid "{uid(ref + ':court')}"))
\t\t(fp_text user "{net_name}" (at 0 3.35 0) (layer "F.Fab") (uuid "{uid(ref + ':label')}") (effects (font (size 0.65 0.65) (thickness 0.08))))
\t\t(pad "S" thru_hole rect (at 0 -1.27) (size 1.6 1.6) (drill 0.8) (layers "*.Cu" "*.Mask") (remove_unused_layers no) (net {net_id} "{net_name}") (pinfunction "SIGNAL") (pintype "passive") (uuid "{uid(ref + ':sig')}"))
\t\t(pad "G" thru_hole circle (at 0 1.27) (size 1.6 1.6) (drill 0.8) (layers "*.Cu" "*.Mask") (remove_unused_layers no) (net 1 "GND") (pinfunction "GUARD") (pintype "passive") (uuid "{uid(ref + ':gnd')}"))
\t\t(model "{MODEL_LED}" (offset (xyz 0 0 0)) (scale (xyz 1 1 1)) (rotate (xyz 0 0 0)))
\t)"""


def testpad(ref: str, x: float, y: float, net_id: int, net_name: str) -> str:
    return f"""
\t(footprint "TP_1.7mm_SMD"
\t\t(layer "F.Cu")
\t\t(uuid "{uid(ref)}")
\t\t(at {x:g} {y:g})
{prop("Reference", ref, "0 -1.6 0", "F.Fab", True)}
{prop("Value", net_name, "0 1.6 0", "F.Fab", True)}
\t\t(attr smd exclude_from_pos_files)
\t\t(fp_circle (center 0 0) (end 1.05 0) (stroke (width 0.08) (type solid)) (fill none) (layer "F.SilkS") (uuid "{uid(ref + ':silk')}"))
\t\t(pad "1" smd circle (at 0 0) (size 1.7 1.7) (layers "F.Cu" "F.Mask") (net {net_id} "{net_name}") (pinfunction "PROBE") (pintype "passive") (uuid "{uid(ref + ':pad')}"))
\t)"""


def pinheader_2x20(ref: str, x: float, y: float) -> str:
    pads = []
    for row in range(20):
        py = (row - 9.5) * 2.54
        pads.append(f'\t\t(pad "{row * 2 + 1}" thru_hole rect (at -1.27 {py:g}) (size 1.7 1.7) (drill 0.95) (layers "*.Cu" "*.Mask") (net {100 + row} "EXP_{row + 1:02d}") (pinfunction "EXP_{row + 1:02d}") (pintype "passive") (uuid "{uid(ref + f":pad{row * 2 + 1}")}"))')
        pads.append(f'\t\t(pad "{row * 2 + 2}" thru_hole circle (at 1.27 {py:g}) (size 1.7 1.7) (drill 0.95) (layers "*.Cu" "*.Mask") (net 1 "GND") (pinfunction "GND") (pintype "passive") (uuid "{uid(ref + f":pad{row * 2 + 2}")}"))')
    return f"""
\t(footprint "Connector_PinHeader_2.54mm:PinHeader_2x20_P2.54mm_Vertical"
\t\t(layer "F.Cu")
\t\t(uuid "{uid(ref)}")
\t\t(at {x:g} {y:g})
{prop("Reference", ref, "0 -28 0", "F.SilkS")}
{prop("Value", "AFE_EXPANSION_2x20", "0 28 0", "F.Fab", True)}
\t\t(attr through_hole)
\t\t(fp_rect (start -3.3 -26.2) (end 3.3 26.2) (stroke (width 0.1) (type solid)) (fill none) (layer "F.SilkS") (uuid "{uid(ref + ':rect')}"))
{chr(10).join(pads)}
\t\t(model "{MODEL_2X20}" (offset (xyz 0 0 0)) (scale (xyz 1 1 1)) (rotate (xyz 0 0 0)))
\t)"""


def pinheader_1x10(ref: str, x: float, y: float) -> str:
    names = ["+5V", "+3V3", "GND", "FRAME_TRIG", "EVENT_SYNC", "ADC_CLK", "I2C_SDA", "I2C_SCL", "SCAN_TTL", "GPIO0"]
    net_lookup = {"+5V": 2, "+3V3": 3, "GND": 1, "FRAME_TRIG": 40, "EVENT_SYNC": 41, "ADC_CLK": 42, "I2C_SDA": 43, "I2C_SCL": 44, "SCAN_TTL": 45, "GPIO0": 46}
    pads = []
    for idx, name in enumerate(names):
        py = (idx - 4.5) * 2.54
        shape = "rect" if idx == 0 else "circle"
        pads.append(f'\t\t(pad "{idx + 1}" thru_hole {shape} (at 0 {py:g}) (size 1.7 1.7) (drill 0.95) (layers "*.Cu" "*.Mask") (net {net_lookup[name]} "{name}") (pinfunction "{name}") (pintype "passive") (uuid "{uid(ref + f":pad{idx + 1}")}"))')
    return f"""
\t(footprint "Connector_PinHeader_2.54mm:PinHeader_1x10_P2.54mm_Vertical"
\t\t(layer "F.Cu")
\t\t(uuid "{uid(ref)}")
\t\t(at {x:g} {y:g})
{prop("Reference", ref, "0 -15 0", "F.SilkS")}
{prop("Value", "SYNC_PWR_1x10", "0 15 0", "F.Fab", True)}
\t\t(attr through_hole)
\t\t(fp_rect (start -1.7 -13.5) (end 1.7 13.5) (stroke (width 0.1) (type solid)) (fill none) (layer "F.SilkS") (uuid "{uid(ref + ':rect')}"))
{chr(10).join(pads)}
\t\t(model "{MODEL_1X10}" (offset (xyz 0 0 0)) (scale (xyz 1 1 1)) (rotate (xyz 0 0 0)))
\t)"""


def soic8(ref: str, x: float, y: float, rot: float = 0) -> str:
    pads = []
    for idx in range(4):
        py = (idx - 1.5) * 1.27
        pads.append(f'\t\t(pad "{idx + 1}" smd roundrect (at -2.7 {py:g} {rot:g}) (size 1.5 0.6) (layers "F.Cu" "F.Paste" "F.Mask") (roundrect_rratio 0.2) (net {120 + idx} "{ref}_P{idx + 1}") (pinfunction "P{idx + 1}") (pintype "passive") (uuid "{uid(ref + f":pad{idx + 1}")}"))')
        pads.append(f'\t\t(pad "{8 - idx}" smd roundrect (at 2.7 {py:g} {rot:g}) (size 1.5 0.6) (layers "F.Cu" "F.Paste" "F.Mask") (roundrect_rratio 0.2) (net {124 + idx} "{ref}_P{8 - idx}") (pinfunction "P{8 - idx}") (pintype "passive") (uuid "{uid(ref + f":pad{8 - idx}")}"))')
    return f"""
\t(footprint "Package_SO:SOIC-8_3.9x4.9mm_P1.27mm"
\t\t(layer "F.Cu")
\t\t(uuid "{uid(ref)}")
\t\t(at {x:g} {y:g} {rot:g})
{prop("Reference", ref, "0 -4 0", "F.SilkS")}
{prop("Value", "TIA_PLACEHOLDER", "0 4 0", "F.Fab", True)}
\t\t(attr smd)
\t\t(fp_rect (start -2 -2.55) (end 2 2.55) (stroke (width 0.12) (type solid)) (fill none) (layer "F.SilkS") (uuid "{uid(ref + ':rect')}"))
{chr(10).join(pads)}
\t\t(model "{MODEL_SOIC}" (offset (xyz 0 0 0)) (scale (xyz 1 1 1)) (rotate (xyz 0 0 0)))
\t)"""


def qfn48(ref: str, x: float, y: float) -> str:
    pads = [f'\t\t(pad "EP" smd rect (at 0 0) (size 4.8 4.8) (layers "F.Cu" "F.Paste" "F.Mask") (net 1 "GND") (pinfunction "EP") (pintype "passive") (uuid "{uid(ref + ":ep")}"))']
    for idx in range(12):
        p = idx + 1
        offset = -2.75 + idx * 0.5
        pads.append(f'\t\t(pad "{p}" smd roundrect (at {offset:g} -3.85) (size 0.28 1.0) (layers "F.Cu" "F.Paste" "F.Mask") (roundrect_rratio 0.2) (net {160 + p} "{ref}_P{p}") (pinfunction "P{p}") (pintype "passive") (uuid "{uid(ref + f":pad{p}")}"))')
        pads.append(f'\t\t(pad "{p + 12}" smd roundrect (at 3.85 {offset:g}) (size 1.0 0.28) (layers "F.Cu" "F.Paste" "F.Mask") (roundrect_rratio 0.2) (net {160 + p + 12} "{ref}_P{p + 12}") (pinfunction "P{p + 12}") (pintype "passive") (uuid "{uid(ref + f":pad{p + 12}")}"))')
        pads.append(f'\t\t(pad "{p + 24}" smd roundrect (at {-offset:g} 3.85) (size 0.28 1.0) (layers "F.Cu" "F.Paste" "F.Mask") (roundrect_rratio 0.2) (net {160 + p + 24} "{ref}_P{p + 24}") (pinfunction "P{p + 24}") (pintype "passive") (uuid "{uid(ref + f":pad{p + 24}")}"))')
        pads.append(f'\t\t(pad "{p + 36}" smd roundrect (at -3.85 {-offset:g}) (size 1.0 0.28) (layers "F.Cu" "F.Paste" "F.Mask") (roundrect_rratio 0.2) (net {160 + p + 36} "{ref}_P{p + 36}") (pinfunction "P{p + 36}") (pintype "passive") (uuid "{uid(ref + f":pad{p + 36}")}"))')
    return f"""
\t(footprint "Package_DFN_QFN:QFN-48-1EP_7x7mm_P0.5mm_EP5.15x5.15mm"
\t\t(layer "F.Cu")
\t\t(uuid "{uid(ref)}")
\t\t(at {x:g} {y:g})
{prop("Reference", ref, "0 -5.4 0", "F.SilkS")}
{prop("Value", "TIMESTAMP_MCU_FPGA_PLACEHOLDER", "0 5.4 0", "F.Fab", True)}
\t\t(attr smd)
\t\t(fp_rect (start -3.7 -3.7) (end 3.7 3.7) (stroke (width 0.12) (type solid)) (fill none) (layer "F.SilkS") (uuid "{uid(ref + ':rect')}"))
{chr(10).join(pads)}
\t\t(model "{MODEL_QFN}" (offset (xyz 0 0 0)) (scale (xyz 1 1 1)) (rotate (xyz 0 0 0)))
\t)"""


def sma(ref: str, x: float, y: float, net_id: int, net_name: str) -> str:
    return f"""
\t(footprint "Connector_Coaxial:SMA_Amphenol_132291_Vertical"
\t\t(layer "F.Cu")
\t\t(uuid "{uid(ref)}")
\t\t(at {x:g} {y:g})
{prop("Reference", ref, "0 -5.5 0", "F.SilkS")}
{prop("Value", net_name, "0 5.5 0", "F.Fab", True)}
\t\t(attr through_hole)
\t\t(fp_circle (center 0 0) (end 4.1 0) (stroke (width 0.12) (type solid)) (fill none) (layer "F.SilkS") (uuid "{uid(ref + ':circle')}"))
\t\t(pad "1" thru_hole circle (at 0 0) (size 2.2 2.2) (drill 1.3) (layers "*.Cu" "*.Mask") (net {net_id} "{net_name}") (pinfunction "SIG") (pintype "passive") (uuid "{uid(ref + ':sig')}"))
\t\t(pad "2" thru_hole circle (at -2.54 -2.54) (size 1.6 1.6) (drill 1.0) (layers "*.Cu" "*.Mask") (net 1 "GND") (pinfunction "GND") (pintype "passive") (uuid "{uid(ref + ':g1')}"))
\t\t(pad "3" thru_hole circle (at 2.54 -2.54) (size 1.6 1.6) (drill 1.0) (layers "*.Cu" "*.Mask") (net 1 "GND") (pinfunction "GND") (pintype "passive") (uuid "{uid(ref + ':g2')}"))
\t\t(pad "4" thru_hole circle (at -2.54 2.54) (size 1.6 1.6) (drill 1.0) (layers "*.Cu" "*.Mask") (net 1 "GND") (pinfunction "GND") (pintype "passive") (uuid "{uid(ref + ':g3')}"))
\t\t(pad "5" thru_hole circle (at 2.54 2.54) (size 1.6 1.6) (drill 1.0) (layers "*.Cu" "*.Mask") (net 1 "GND") (pinfunction "GND") (pintype "passive") (uuid "{uid(ref + ':g4')}"))
\t\t(model "{MODEL_SMA}" (offset (xyz 0 0 0)) (scale (xyz 1 1 1)) (rotate (xyz 0 0 0)))
\t)"""


def zone(layer: str) -> str:
    return f"""
\t(zone
\t\t(net 1)
\t\t(net_name "GND")
\t\t(layer "{layer}")
\t\t(uuid "{uid('zone:' + layer)}")
\t\t(hatch edge 0.508)
\t\t(connect_pads yes (clearance 0.35))
\t\t(min_thickness 0.254)
\t\t(filled_areas_thickness no)
\t\t(fill yes (thermal_gap 0.508) (thermal_bridge_width 0.508))
\t\t(polygon
\t\t\t(pts
\t\t\t\t(xy 50 55) (xy 155 55) (xy 155 145) (xy 50 145)
\t\t\t)
\t\t)
\t)"""


def detector_positions() -> list[tuple[int, int]]:
    return [
        (-3, -3), (0, -3), (3, -3),
        (-1, -2), (1, -2),
        (-2, -1), (0, -1), (2, -1),
        (-3, 0), (-1, 0), (1, 0), (3, 0),
        (-2, 1), (0, 1), (2, 1),
        (-1, 2), (1, 2),
        (-3, 3), (0, 3), (3, 3),
        (0, 0),
    ]


def board_text() -> str:
    nets = ['\t(net 0 "")', '\t(net 1 "GND")', '\t(net 2 "+5V")', '\t(net 3 "+3V3")']
    for idx in range(21):
        nets.append(f'\t(net {10 + idx} "SP{idx + 1:02d}")')
    for net_id, name in [(40, "FRAME_TRIG"), (41, "EVENT_SYNC"), (42, "ADC_CLK"), (43, "I2C_SDA"), (44, "I2C_SCL"), (45, "SCAN_TTL"), (46, "GPIO0"), (47, "SYNC_IN"), (48, "SYNC_OUT")]:
        nets.append(f'\t(net {net_id} "{name}")')
    for idx in range(20):
        nets.append(f'\t(net {100 + idx} "EXP_{idx + 1:02d}")')
    for idx in range(80):
        nets.append(f'\t(net {120 + idx} "LOCAL_{idx + 1:02d}")')

    footprints = [
        mounting_hole("H1", 57, 62),
        mounting_hole("H2", 148, 62),
        mounting_hole("H3", 148, 138),
        mounting_hole("H4", 57, 138),
        pinheader_2x20("J1", 145, 100),
        pinheader_1x10("J2", 55, 100),
        soic8("U1", 128, 76, 90),
        soic8("U2", 128, 100, 90),
        soic8("U3", 128, 124, 90),
        qfn48("U4", 111, 137),
        sma("J3", 67, 137, 47, "SYNC_IN"),
        sma("J4", 83, 137, 48, "SYNC_OUT"),
    ]
    segments = []
    detector_ground_rows: dict[float, list[float]] = {}
    pitch = 8.5
    center_x, center_y = 91, 100
    for idx, (gx, gy) in enumerate(detector_positions(), start=1):
        x = center_x + gx * pitch
        y = center_y + gy * pitch
        net_id = 10 + idx - 1
        net_name = f"SP{idx:02d}"
        tp_x = x + 3.8
        tp_y = y - 1.27
        footprints.append(detector(f"PD{idx:02d}", x, y, net_id, net_name))
        footprints.append(testpad(f"TP{idx:02d}", tp_x, tp_y, net_id, net_name))
        segments.append(track(f"seg:sp{idx}", "F.Cu", x, y - 1.27, tp_x, tp_y, net_id, 0.22))
        detector_ground_rows.setdefault(round(y + 1.27, 3), []).append(x)

    left_bus_x = 60.5
    right_bus_x = 146.27
    top_bus_y = 66.5
    for row_idx, (ground_y, xs) in enumerate(sorted(detector_ground_rows.items())):
        segments.append(track(f"gnd:det-row:{row_idx}", "B.Cu", left_bus_x, ground_y, max(xs), ground_y, 1, 0.45))
    segments.extend(
        [
            track("gnd:left-bus", "B.Cu", left_bus_x, top_bus_y, left_bus_x, 139.54, 1, 0.55),
            track("gnd:top-tie", "B.Cu", left_bus_x, top_bus_y, right_bus_x, top_bus_y, 1, 0.55),
            track("gnd:j1-bus", "B.Cu", right_bus_x, top_bus_y, right_bus_x, 124.13, 1, 0.55),
            track("gnd:j2", "B.Cu", 55.0, 93.65, left_bus_x, 93.65, 1, 0.55),
            track("gnd:sma-top", "B.Cu", left_bus_x, 134.46, 85.54, 134.46, 1, 0.55),
            track("gnd:sma-bottom", "B.Cu", left_bus_x, 139.54, 85.54, 139.54, 1, 0.55),
            via("gnd:u4-ep-via", 111, 137, 1),
            track("gnd:u4-vertical", "B.Cu", 111, 137, 111, 132, 1, 0.45),
            track("gnd:u4-return", "B.Cu", left_bus_x, 132, 111, 132, 1, 0.45),
        ]
    )

    drawings = [
        gr_rect("Edge.Cuts", 50, 55, 155, 145, "edge", 0.15),
        gr_rect("Dwgs.User", 62, 70, 120, 130, "sensor-island", 0.18),
        gr_rect("F.Fab", 63.5, 71.5, 118.5, 128.5, "sensor-active", 0.10),
        '\t(gr_text "HybridImager V1 Weiqi Sparse Sensor" (at 102 59.5 0) (layer "F.SilkS") (uuid "' + uid("text:title") + '") (effects (font (size 1.4 1.4) (thickness 0.18))))',
        '\t(gr_text "21 sparse single-pixel sites; AFE placeholders; sync first" (at 102 142 0) (layer "F.SilkS") (uuid "' + uid("text:subtitle") + '") (effects (font (size 0.95 0.95) (thickness 0.13))))',
        '\t(gr_text "Detector island" (at 91 68 0) (layer "F.SilkS") (uuid "' + uid("text:detector") + '") (effects (font (size 0.9 0.9) (thickness 0.12))))',
        '\t(gr_text "AFE placeholders" (at 129 63 0) (layer "F.SilkS") (uuid "' + uid("text:afe") + '") (effects (font (size 0.8 0.8) (thickness 0.11))))',
    ]

    return f"""(kicad_pcb
\t(version 20240108)
\t(generator "hybridimager-v1-generator")
\t(generator_version "1.0")
\t(general
\t\t(thickness 1.6)
\t\t(legacy_teardrops no)
\t)
\t(paper "A4")
\t(title_block
\t\t(title "HybridImager V1 Weiqi Sparse Sensor Board")
\t\t(date "2026-06-08")
\t\t(rev "0.1.0-draft")
\t\t(company "LazyingArt LLC / HybridImager")
\t)
\t(layers
\t\t(0 "F.Cu" signal)
\t\t(31 "B.Cu" signal)
\t\t(32 "B.Adhes" user "B.Adhesive")
\t\t(33 "F.Adhes" user "F.Adhesive")
\t\t(34 "B.Paste" user)
\t\t(35 "F.Paste" user)
\t\t(36 "B.SilkS" user "B.Silkscreen")
\t\t(37 "F.SilkS" user "F.Silkscreen")
\t\t(38 "B.Mask" user)
\t\t(39 "F.Mask" user)
\t\t(40 "Dwgs.User" user "User.Drawings")
\t\t(41 "Cmts.User" user "User.Comments")
\t\t(42 "Eco1.User" user "User.Eco1")
\t\t(43 "Eco2.User" user "User.Eco2")
\t\t(44 "Edge.Cuts" user)
\t\t(45 "Margin" user)
\t\t(46 "B.CrtYd" user "B.Courtyard")
\t\t(47 "F.CrtYd" user "F.Courtyard")
\t\t(48 "B.Fab" user)
\t\t(49 "F.Fab" user)
\t\t(50 "User.1" user)
\t\t(51 "User.2" user)
\t\t(52 "User.3" user)
\t\t(53 "User.4" user)
\t\t(54 "User.5" user)
\t\t(55 "User.6" user)
\t\t(56 "User.7" user)
\t\t(57 "User.8" user)
\t\t(58 "User.9" user)
\t)
\t(setup
\t\t(pad_to_mask_clearance 0.05)
\t\t(allow_soldermask_bridges_in_footprints no)
\t\t(pcbplotparams
\t\t\t(layerselection 0x00010fc_ffffffff)
\t\t\t(usegerberextensions no)
\t\t\t(usegerberattributes yes)
\t\t\t(usegerberadvancedattributes yes)
\t\t\t(creategerberjobfile yes)
\t\t\t(outputformat 1)
\t\t\t(outputdirectory "gerber/")
\t\t)
\t)
{chr(10).join(nets)}
{chr(10).join(footprints)}
{chr(10).join(drawings)}
{chr(10).join(segments)}
{zone("B.Cu")}
)"""


def schematic_text() -> str:
    return f"""(kicad_sch
\t(version 20231120)
\t(generator "hybridimager-v1-generator")
\t(generator_version "1.0")
\t(uuid "{uid("schematic")}")
\t(paper "A4")
\t(title_block
\t\t(title "HybridImager V1 Weiqi Sparse Sensor Board")
\t\t(date "2026-06-08")
\t\t(rev "0.1.0-draft")
\t)
\t(lib_symbols)
\t(text "Board-first schematic stub. V1 validates sparse single-pixel placement, sync connectors, and AFE/mezzanine mechanical space before detailed analog design." (at 30 40 0)
\t\t(effects (font (size 1.27 1.27)) (justify left bottom))
\t\t(uuid "{uid("sch:text")}")
\t)
\t(sheet_instances (path "/" (page "1")))
)"""


def project_text() -> str:
    return json.dumps(
        {
            "meta": {"filename": PROJECT.name, "version": 1},
            "board": {
                "design_settings": {
                    "rule_severities": {
                        "lib_footprint_mismatch": "ignore",
                        "lib_footprint_issues": "ignore",
                        "missing_courtyard": "ignore",
                        "silk_over_copper": "ignore",
                    }
                }
            },
        },
        indent=2,
    ) + "\n"
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

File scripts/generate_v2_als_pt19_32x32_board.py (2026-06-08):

#!/usr/bin/env python3
"""Generate the HybridImager V2 aligned 32x32 ALS-PT19 sensor-board draft."""

from __future__ import annotations

import csv
import json
import math
import shutil
import uuid
from pathlib import Path

import matplotlib.pyplot as plt
import numpy as np
from mpl_toolkits.mplot3d.art3d import Poly3DCollection


ROOT = Path(__file__).resolve().parents[1]
OUT_DIR = ROOT / "hardware/v2-als-pt19-32x32"
ARTIFACT_DIR = OUT_DIR / "artifacts"
GERBER_DIR = OUT_DIR / "gerber"
BOARD_NAME = "hybridimager-v2-als-pt19-32x32"
BOARD = OUT_DIR / f"{BOARD_NAME}.kicad_pcb"
PROJECT = OUT_DIR / f"{BOARD_NAME}.kicad_pro"
SCHEMATIC = OUT_DIR / f"{BOARD_NAME}.kicad_sch"
FP_LIB_TABLE = OUT_DIR / "fp-lib-table"
DATASET = OUT_DIR / "hybridimager-v2-source-dataset.json"
BOM = OUT_DIR / "hybridimager-v2-bom.csv"
README = OUT_DIR / "README.md"
LOCAL_GITIGNORE = OUT_DIR / ".gitignore"
PREVIEW = ARTIFACT_DIR / "hybridimager-v2-full-view-render.png"

GRID = 32
PITCH = 2.54
X0 = 55.0
Y0 = 48.0
PAD_ROW_DX = -0.75
PAD_COL_DX = 0.75
ROW_BUS_DY = -0.72
COL_VIA_DY = 0.72
ROW_HEADER_X = 28.0
COL_HEADER_Y = 29.0
BOARD_MIN_X = 18.0
BOARD_MIN_Y = 18.0
BOARD_MAX_X = 174.0
BOARD_MAX_Y = 146.0


def uid(name: str) -> str:
    return str(uuid.uuid5(uuid.NAMESPACE_URL, f"lazyingart:hybridimager:{BOARD_NAME}:{name}"))


def prop(name: str, value: str, at: str, layer: str = "F.Fab", hide: bool = False) -> str:
    hidden = "\n\t\t\t(hide yes)" if hide else ""
    return f"""\t\t(property "{name}" "{value}"
\t\t\t(at {at})
\t\t\t(layer "{layer}"){hidden}
\t\t\t(uuid "{uid(f'prop:{name}:{value}:{at}:{layer}')}")
\t\t\t(effects (font (size 0.9 0.9) (thickness 0.12)))
\t\t)"""


def gr_line(layer: str, x1: float, y1: float, x2: float, y2: float, name: str, width: float = 0.12) -> str:
    return f'\t(gr_line (start {x1:g} {y1:g}) (end {x2:g} {y2:g}) (stroke (width {width:g}) (type solid)) (layer "{layer}") (uuid "{uid(name)}"))'


def gr_rect(layer: str, x1: float, y1: float, x2: float, y2: float, name: str, width: float = 0.12) -> str:
    return "\n".join(
        [
            gr_line(layer, x1, y1, x2, y1, f"{name}:top", width),
            gr_line(layer, x2, y1, x2, y2, f"{name}:right", width),
            gr_line(layer, x2, y2, x1, y2, f"{name}:bottom", width),
            gr_line(layer, x1, y2, x1, y1, f"{name}:left", width),
        ]
    )


def track(name: str, layer: str, x1: float, y1: float, x2: float, y2: float, net_id: int, width: float = 0.2) -> str:
    return f'\t(segment (start {x1:g} {y1:g}) (end {x2:g} {y2:g}) (width {width:g}) (layer "{layer}") (net {net_id}) (uuid "{uid(name)}"))'


def via(name: str, x: float, y: float, net_id: int) -> str:
    return f'\t(via (at {x:g} {y:g}) (size 0.6) (drill 0.3) (layers "F.Cu" "B.Cu") (net {net_id}) (uuid "{uid(name)}"))'


def row_net(row: int) -> tuple[int, str]:
    return 10 + row, f"ROW{row + 1:02d}"


def col_net(col: int) -> tuple[int, str]:
    return 50 + col, f"COL{col + 1:02d}"


def grid_xy(col: int, row: int) -> tuple[float, float]:
    return X0 + col * PITCH, Y0 + row * PITCH


def als_pt19(ref: str, x: float, y: float, row_id: int, row_name: str, col_id: int, col_name: str) -> str:
    return f"""
\t(footprint "ALS-PT19"
\t\t(layer "F.Cu")
\t\t(uuid "{uid(ref)}")
\t\t(at {x:g} {y:g})
\t\t(descr "ALS-PT19 phototransistor footprint copied from CustomSensor/digiOBSCURA geometry")
\t\t(tags "ALS-PT19 phototransistor 32x32 aligned")
{prop("Reference", ref, "0 1.35 0", "F.Fab", True)}
{prop("Value", "ALS-PT19", "0 -1.35 0", "F.Fab", True)}
\t\t(attr smd)
\t\t(fp_rect (start -1.2 -0.4) (end 1.2 0.4) (stroke (width 0.06) (type solid)) (fill none) (layer "F.Fab") (uuid "{uid(ref + ':fab')}"))
\t\t(fp_line (start 0.3 -0.4) (end 0.3 0.4) (stroke (width 0.05) (type solid)) (layer "F.Fab") (uuid "{uid(ref + ':mark')}"))
\t\t(pad "1" smd rect (at -0.75 0) (size 0.8 0.8) (layers "F.Cu" "F.Paste" "F.Mask") (net {row_id} "{row_name}") (pinfunction "ROW") (pintype "passive") (uuid "{uid(ref + ':row')}"))
\t\t(pad "2" smd rect (at 0.75 0) (size 0.8 0.8) (layers "F.Cu" "F.Paste" "F.Mask") (net {col_id} "{col_name}") (pinfunction "COL") (pintype "passive") (uuid "{uid(ref + ':col')}"))
\t)"""


def aligned_row_header() -> str:
    pads = []
    for row in range(GRID):
        net_id, net_name = row_net(row)
        _, y = grid_xy(0, row)
        pads.append(
            f'\t\t(pad "{row + 1}" thru_hole oval (at {ROW_HEADER_X:g} {y:g}) (size 1.55 1.15) (drill 0.7) (layers "*.Cu" "*.Mask") (net {net_id} "{net_name}") (pinfunction "{net_name}") (pintype "passive") (uuid "{uid(f"JROW:pad{row + 1}")}"))'
        )
    return f"""
\t(footprint "Aligned_Row_Header_1x32_2.54mm"
\t\t(layer "F.Cu")
\t\t(uuid "{uid('JROW')}")
\t\t(at 0 0)
{prop("Reference", "JROW", f"{ROW_HEADER_X:g} {Y0 - 5:g} 0", "F.SilkS")}
{prop("Value", "ROW_EDGE_1x32_ALIGNED", f"{ROW_HEADER_X:g} {Y0 + GRID * PITCH + 2:g} 0", "F.Fab", True)}
\t\t(attr through_hole)
{chr(10).join(pads)}
\t)"""


def aligned_col_header() -> str:
    pads = []
    for col in range(GRID):
        net_id, net_name = col_net(col)
        x, _ = grid_xy(col, 0)
        x += PAD_COL_DX
        pads.append(
            f'\t\t(pad "{col + 1}" thru_hole oval (at {x:g} {COL_HEADER_Y:g} 90) (size 1.55 1.15) (drill 0.7) (layers "*.Cu" "*.Mask") (net {net_id} "{net_name}") (pinfunction "{net_name}") (pintype "passive") (uuid "{uid(f"JCOL:pad{col + 1}")}"))'
        )
    return f"""
\t(footprint "Aligned_Col_Header_1x32_2.54mm"
\t\t(layer "F.Cu")
\t\t(uuid "{uid('JCOL')}")
\t\t(at 0 0)
{prop("Reference", "JCOL", f"{X0 + 34:g} {COL_HEADER_Y - 4:g} 0", "F.SilkS")}
{prop("Value", "COL_EDGE_1x32_ALIGNED", f"{X0 + 34:g} {COL_HEADER_Y + 4:g} 0", "F.Fab", True)}
\t\t(attr through_hole)
{chr(10).join(pads)}
\t)"""


def control_header() -> str:
    names = ["A0", "A1", "A2", "A3", "A4", "ROW_CS", "COL_CS", "WR", "EN", "OUTROW", "OUTCOL", "+3V3", "GND"]
    net_lookup = {name: 90 + idx for idx, name in enumerate(names)}
    net_lookup["+3V3"] = 2
    net_lookup["GND"] = 1
    pads = []
    x = 161.5
    y0 = 55.0
    for idx, name in enumerate(names):
        y = y0 + idx * 3.0
        shape = "rect" if idx == 0 else "oval"
        pads.append(
            f'\t\t(pad "{idx + 1}" thru_hole {shape} (at {x:g} {y:g}) (size 1.6 1.2) (drill 0.75) (layers "*.Cu" "*.Mask") (net {net_lookup[name]} "{name}") (pinfunction "{name}") (pintype "passive") (uuid "{uid(f"JCTL:pad{idx + 1}")}"))'
        )
    return f"""
\t(footprint "Control_Header_1x13_3mm"
\t\t(layer "F.Cu")
\t\t(uuid "{uid('JCTL')}")
\t\t(at 0 0)
{prop("Reference", "JCTL", f"{x:g} {y0 - 5:g} 0", "F.SilkS")}
{prop("Value", "ADDR_SYNC_PWR", f"{x:g} {y0 + len(names) * 3:g} 0", "F.Fab", True)}
\t\t(attr through_hole)
{chr(10).join(pads)}
\t)"""
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

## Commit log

2026-06-08 Initialize hybrid camera research package
    [digiobscura.kicad_pcb, digiobscura.sch, digiobscura_mcu.kicad_pcb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]
2026-06-08 Add open camera project survey
2026-06-08 Add V1 Weiqi sparse sensor board
    [hybridimager-v1-bom.csv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]
2026-06-08 Add V2 ALS-PT19 aligned matrix board
    [hybridimager-v2-als-pt19-32x32-B_Cu.gbl, hybridimager-v2-als-pt19-32x32-B_Fab.gbr, hybridimager-v2-als-pt19-32x32-B_Mask.gbs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]

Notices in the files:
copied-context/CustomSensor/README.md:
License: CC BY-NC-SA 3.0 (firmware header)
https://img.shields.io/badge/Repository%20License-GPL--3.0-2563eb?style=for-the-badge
